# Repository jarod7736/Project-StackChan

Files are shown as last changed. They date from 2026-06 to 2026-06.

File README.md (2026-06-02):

# Project Stack-chan

Voice-interactive M5Stack CoreS3 desk companion. See
[`docs/superpowers/specs/2026-06-02-stackchan-design.md`](docs/superpowers/specs/2026-06-02-stackchan-design.md)
for the full design and
[`docs/superpowers/plans/2026-06-02-stackchan-v1.md`](docs/superpowers/plans/2026-06-02-stackchan-v1.md)
for the v1 implementation plan.

## Build

```
pio run                 # firmware
pio run -t upload       # flash via USB
pio run -t uploadfs     # captive-portal UI to LittleFS
pio test -e native      # host-side unit tests
```

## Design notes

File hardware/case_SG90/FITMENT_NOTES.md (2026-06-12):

# SG90 head case — fitment notes + edit plan

## What's in this directory

Vendored copy of the **official stack-chan v1.0 SG90 case** (the editable source for
the head), pulled from
`stack-chan/stack-chan` @ branch `dev/v1.0`, path `case/case_SG90/`.

| File | What |
|---|---|
| `shell_SG90.step` / `.stl` | head shell (face housing) |
| `bracket_SG90.step`, `bracket_SG90_f.stl`, `bracket_SG90_b.stl` | **servo bracket — a SEPARATE part** (front + back halves) |
| `feet_SG90.step` / `.stl` | base interface (stock, no mounting holes) |
| `feet_SG90M.*`, `feet_MG90S2M.*` | **screw-down feet variants** for `../enclosure/pedestal-sg90` — generated by `make_feet_mounting.py` (see "Feet M variants" below) |
| `UPSTREAM_README.md` | upstream readme (print settings, assembly) |

**License/attribution:** upstream `stack-chan/stack-chan` is **Apache-2.0**. These files
are redistributed under that license; credit to the stack-chan project. Source:
https://github.com/stack-chan/stack-chan/tree/dev/v1.0/case/case_SG90

## The problem (assembly finding, 2026-06-10)

On the current (older/Takao) head the **servo mount is integrated into the head mesh**,
so the CoreS3 + battery and the servo mount fight for the same front space — they don't
both fit. A fixed STL can't be reshaped cleanly. **This v1.0 SG90 case is the way
forward because its servo bracket is a *separate part*** — you can move/modify the
bracket without touching the shell.

## Options (pick by effort)

**B — no CAD, fastest (do this first): move the battery to the rear.**
Mount the LiPo on the *back* of the head (printed clip or velcro). This frees the front
cavity for the CoreS3 alone AND counterweights the heavy face so the SG90 pitch servo
isn't fighting gravity (no droop / nose-dive — which is also why we clipped pitch-down to
-12 in firmware). Often enough on its own.

**A — CAD change (the real fix), in Fusion 360.** STEP imports as a B-rep solid *body*
with no timeline history, so you edit the body directly:
- **Shift the servo mount back:** open `bracket_SG90.step`, select the bracket body, use
  **Modify → Move/Copy** to translate it rearward (−Y / toward the back) by the clearance
  you need; re-check it still mates to the shell and feet. (Bracket is separate → low risk.)
- **Or deepen the shell:** open `shell_SG90.step`, **Modify → Press Pull** (or **Offset
  Face**) on the front/back face to add depth to the cavity.
- Move/Copy, Press Pull, Offset Face, Align, Combine all work on imported no-history
  bodies. Docs:
  - Solid modify tools: https://help.autodesk.com/cloudhelp/ENU/Fusion-Model/files/SLD-MODIFY-SOLID-BODY.htm
  - Press Pull: https://help.autodesk.com/cloudhelp/ENU/Fusion-Model/files/GUID-02F9ADA3-7556-42A9-8AD1-552728D537AB.htm
  - (Imported bodies w/o history are listed as a Scale/Press-Pull use case in the Modify docs.)

## Target regardless of path

Get the **combined CoreS3 + battery center of mass roughly over the pitch servo shaft.**
That's what keeps the weak SG90 from straining and the head from nose-diving. "Battery to
rear" and "bracket back + battery rear" both aim at this; "deeper head" lets you place the
face so the CG lands on the pivot.

## Status

- Files vendored + this plan recorded (2026-06-10).
- The actual geometry edit is a Fusion task on your machine (no CAD tooling in the dev env).
- Electronics/firmware side is DONE and unaffected (see `2026-06-09-servo-bringup-handoff.md`).

## MG90S — DOES NOT FIT THIS BRACKET (2026-06-12, supersedes 2026-06-11)

The 2026-06-11 `bracket_MG90S` variant (slots translated 2mm along shaft axes) was
**wrong and has been deleted** (recoverable from git history, commit 2485899).
Physical fit failed; full geometric analysis of `bracket_SG90.step` shows **no slot
position works** — see `analysis/mg90s_no_fit.png`.

**Measured bracket facts** (coordinates of the vendored STEP):

- Pan servo (shaft −Z): flange slot Z 3.27–5.95 (2.68mm), head pocket 4.1mm deep
  (floor Z −0.83 = skin top), body channel X[−6.92, 5.46] × Y[−10.77, 12.31]
  (12.38 × 23.08). Body top pokes through a wall at Z 19.96–21.92.
- Tilt servo (shaft +X): mirror-image of pan: slot X 6.88–9.56, pocket to 13.66,
  skin to 15.62. **The tilt cavity floor (Z 21.92) is the pan cavity ceiling** —
  an SG90 pan body (15.7mm below tab) ends at Z 21.65, 0.27mm under the tilt servo.
- Pan shaft at (X −0.73, Y −4.7); tilt axis at (Y −4.7, Z 28.15).
- **Left head-pivot boss**: Ø5.2 tube on the tilt axis, X −25.5 to −12.87, with a
  screw bore. The shell's left side hinges on it. It cannot move (shell interface)
  and the tilt axis passes through any tilt servo's body.

**Why MG90S (user-measured drawing: 24L × 12.5W; 20 below-tab + 3 tab + 1 shelf +
6 head + 4 spline) cannot fit, in either position:**

- Pan: vertical budget from feet-horn plane (Z −0.83) to tilt cavity floor (21.92)
  is **22.75mm**; MG90S case needs **30mm** → crashes 7.25mm into the tilt servo.
- Tilt: horizontal budget from right skin (13.66) to left wall (−8.88) is
  **22.54mm** (26.5 if the wall is cut — but the pivot boss root starts there);
  same 30mm need → ≥3.5mm short, into the head's own hinge.
- Independent minor blockers: 3mm tabs vs 2.68 slots; 24 × 12.5 body vs
  23.08 × 12.38 channels.
- Slot translation trades horn position 1:1 and fixes nothing; the 06-11 edit also
  left the horns ~4mm out of design position.

**Max servo envelope this bracket accepts** (horn at design position; caliper any
candidate servo against this BEFORE buying/printing):

| dimension | max |
|---|---|
| body length × width | 23.0 × 12.3 |
| below-tab body length | 15.7 |
| tab thickness | 2.6 (3.0 possible with +0.5 slot-widen edit) |
| tab span | ≤32.5 (longer pokes out the open slot bands) |
| tab-underside → case top (shaft side) | 4.1 |
| spline | 21T, ~3.2mm engagement |

i.e. true SG90/MS18-envelope servos only. Anything taller below the tab or above
it does not fit, full stop.

**Paths to metal gears:** (a) find a metal-gear servo inside the envelope above
(verify with calipers — "MG90S" clone dimensions vary wildly and the common claim
that MG90S = SG90 size is false along the shaft axis); (b) redesign bracket + feet
+ pedestal around bigger servos — a new-body project, not a bracket edit (upstream's
RS30X/SCS0009 cases show the scale of that); (c) keep MS18-class and manage load in
firmware (current approach: pitch clipped to −12).

→ Path (b) was executed 2026-06-12 as the **MG90S2 taller-bracket set** below.

## MG90S2 — taller bracket set that DOES fit MG90S (2026-06-12)

User authorized growing the bracket. Generated by `make_mg90s2.py` (committed;
re-run it to regenerate after dimension tweaks). All booleans volume-asserted;
STLs watertight; **virtual MG90S pan+tilt solids verified non-intersecting with
both halves and each other.** Verification renders: `analysis/MG90S2_*.png`.

**Print/replace:** `bracket_MG90S2_f.stl` + `bracket_MG90S2_b.stl` (instead of
the SG90 bracket) and `feet_MG90S2.stl` (instead of `feet_SG90.stl`).
`shell_SG90` is UNCHANGED.

What changed vs stock (all derived from the user's MG90S drawing:
24L × 12.5W; 20 below-tab + 3 tab + 1+6 head + 4 spline; 34 tab span):

- **+7.55mm taller** via two prismatic stretches (+2.90 in the pan pocket zone →
  pocket depth exactly 7.0; +4.65 in the pan channel zone → tilt cavity floor
  at Z 29.47, clearing the pan body top 29.17 by 0.3).
- Pan slot now Z 6.17–9.32 (3.15 for the 3.0 tab); both body windows enlarged to
  25.0 × 12.8 (the 0.5 length slack tolerates shaft-offset clone variance
  5.5–6.5mm); tab wing paths opened for the 34mm span.
- Tilt slot moved inboard to X 3.51–6.66; the body passes through the left wall
  and protrudes 5.5mm into a **shroud box** which **re-roots the left pivot
  boss** — boss axis, screw end (X −24.74) and bearing length (covers the
  shell's |X| 19.9–26.1 hub) are unchanged.
- Pan + tilt horn/spline planes are at the stock design positions; cable
  notches extended (pan front wall) / added (shroud side ribs, both sides).
- Feet: Ø5.4 relief, 2mm deeper at recess center, for the 0.8mm-longer spline.

**Assembly notes:**

- The tilt axis is now at Z 35.70 (was 28.15). The shell has THREE pivot holes
  at 8mm pitch — **mount the shell one hole lower than before**; net face height
  change ≈ −0.45mm. Everything else about shell mounting is unchanged.
- No snap nubs in the new slots (stock nubs were SG90-specific): servos are held
  by slot clamping once the halves are screwed — normal for this design.
- Cosmetic: the 34mm tab spans poke 0.4–1.2mm out of the open slot bands; the
  tilt servo's motor end is enclosed by the new shroud on the left.
- First assembly: check the horn cups (feet + shell) accept the 0.8mm-extra
  spline depth; the feet relief covers the pan side, shell cup depth unverified.

## Feet "M" variants — screw-down mounting for the pedestal (2026-06-12)

`make_feet_mounting.py` generates `feet_SG90M` and `feet_MG90S2M` (STEP + STL):
the stock feet with **4× Ø1.6 × 6.5 mm pilot holes** drilled up from the bottom
face at feet-local **(±12.5, −18)** and **(±12.5, +10)** (hub = origin). Print
these instead of the stock feet when using `../enclosure/pedestal-sg90`.

Why: the pedestal recess was sized 54×50 from the *Takao* feet, but the vendored
v1.0 `feet_SG90` actually measures **48 × 37 × 8.2 mm** (rounded-rect r2.0; bbox
center 4.5 mm off the hub; 2 mm-wide full-height cable slot on one edge; horn
pocket floor at Z 5.7). The reworked pedestal (same 2026-06-12 change) has a
48.4 × 37.4 recess with a 2 mm floor, a back wire slot, and 4 matching Ø2.4
clearance holes — the feet drop in (cable slot toward the barrel jack; the
offset recess keys the orientation) and are retained by **4× M2×8 pan-heads
driven from inside the cavity**. Hole spots were ray-cast verified solid through
the full 8.2 mm height; 6.5 mm pilots clear the horn pocket (which the pattern
avoids entirely). The pan-horn M2×8 stays serviceable through the pedestal's
Ø22 center hole.

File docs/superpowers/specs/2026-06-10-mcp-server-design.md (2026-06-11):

# On-device MCP server — design

**Date:** 2026-06-10 (rev 2 — advisor review applied)
**Status:** approved design, advisor-reviewed; awaiting owner spec sign-off

## 1. Summary

Expose StackChan's abilities as Model Context Protocol tools served from the robot
itself, so MCP clients (Claude Code first) can drive it:

```
claude mcp add --transport http stackchan http://192.168.1.121/mcp
```

(IP, not `stackchan.local` — mDNS is unreliable from WSL2, where Claude Code runs
here. mDNS still works for other clients.)

Inspired by upstream `stack-chan/stack-chan` `services/mcp-server` (Moddable/TS);
re-implemented natively for our AsyncWebServer/C++ firmware.

**Deployment context:** the LAN AI host is about to grow — a Ryzen AI Max box
(128 GB RAM, NPU running Lemonade's OpenAI-compatible server) will take over
local model serving from the current Ollama host. Local agents on that box are
expected MCP clients too, not just Claude Code. Nothing in this design assumes a
particular client or cloud; all the robot's AI endpoints stay NVS-configurable
(`chat_host` etc. — see §8).

## 2. Goals & non-goals

**Goals**
- MCP Streamable HTTP endpoint at `POST /mcp`, JSON-RPC 2.0, stateless JSON mode
  (single JSON response per request; no SSE, no sessions, no auth — matches the
  existing open-LAN posture of `/api/control/*`).
- Four v1 tools: `say`, `set_expression`, `move_head`, `get_status`.
- Easy expansion: tools live in one static table (name, description, input
  schema, handler); adding a tool is one entry + one handler.
- Heap-safe on a device whose internal RAM is razor thin with vision enabled.

**Non-goals (v1)**
- `take_photo` (≈200 KB base64 responses starve LwIP; revisit with chunking).
- SSE / server-initiated messages, sessions, resumability, auth.
- MCP resources/prompts capabilities (tools only).
- JSON-RPC batch arrays (legal only pre-2025-06-18; we reject with `-32600`).

## 3. Architecture

New module `src/services/McpServer.{h,cpp}`:

- `McpServer::attach(AsyncWebServer&)` called from `CaptivePortal` when the LAN
  control server starts (LAN mode only, after WiFi join).
- `POST /mcp` body handling (async_tcp task):
  - Per-request accumulation buffer attached via `request->_tempObject` — NOT a
    shared global (the existing `g_pending_config` single-global pattern has a
    latent interleaving bug with concurrent clients; do not copy it).
  - Cap 4096 bytes: on the first chunk, if `total > 4096`, and on every chunk if
    `index + len > 4096` (covers chunked transfer with no Content-Length), send
    `413`, mark the request rejected, and `request->client()->close()` so the
    remaining inflow doesn't drain through LwIP.
- **Dispatch order (normative):**
  1. Parse JSON. Malformed → `-32700` (HTTP 200, `id: null`).
  2. Batch array → `-32600`.
  3. **No `id` member → HTTP `202`, empty body, regardless of method.** This
     covers `notifications/initialized`, `notifications/cancelled`,
     `notifications/roots/list_changed`, and anything else Claude Code emits.
     Notifications NEVER receive a JSON-RPC response or error.
  4. Only `id`-bearing requests reach the method table.

| method | behavior |
|---|---|
| `initialize` | echo the client's `protocolVersion` if it is one of {`2024-11-05`, `2025-03-26`, `2025-06-18`}, else respond `2025-06-18`; capabilities `{tools:{}}`; serverInfo name `stackchan`, version `1.0.0` |
| `tools/list` | tool table with JSON Schemas |
| `tools/call` | dispatch to handler (§4) |
| `ping` | `{}` result |
| anything else (with `id`) | JSON-RPC `-32601` |

- `GET /mcp` → `405`.
- **HTTP status policy:** every JSON-RPC envelope — results AND protocol errors
  (`-32700` … `-32603`) — ships as **HTTP 200** `Content-Type: application/json`.
  Non-200 is reserved for: `202` notifications, `413` body cap, `405` GET, `403`
  Origin rejection. (A 4xx on `initialize` would trip Claude Code's legacy
  HTTP+SSE fallback probe and fail the connection uselessly.)
- **Headers:** `MCP-Protocol-Version` request header is accepted and ignored.
  `Accept` is ignored (curl-friendly). `Mcp-Session-Id` is never issued.
  JSON-RPC `id` is echoed with its original type (number or string).
- **Origin:** if an `Origin` header is present and its host is not a private-LAN
  address, `.local` name, or `localhost`, respond `403` (cheap DNS-rebinding
  guard; non-browser clients send no Origin and are unaffected).

**Memory:** all `JsonDocument`s (parse + response) use an ArduinoJson v7 custom
`Allocator` backed by `ps_malloc` (PSRAM), as do the accumulation and serialized
output buffers. Transient internal-heap cost per request must stay under ~2 KB;
`tools/list` (the largest response, ~2–4 KB serialized) must not allocate it
from internal heap. The protocol core's transient serialization std::string and the HTTP library's response copy (each ≤4 KB internal, freed within the request) are accepted; the JsonDocuments — the dominant allocation — are PSRAM-backed.

**Thread-safety:** handlers run on the async_tcp task. All effects route through
the `ControlBridge` queue (executed on the main task). `get_status` reads only
snapshot values (same fields `/api/control/state` and `/api/debug/presence`
already expose from this task). No handler calls `requestExternalSpeak`,
`face`, `motion`, or `servos` directly.

## 4. Tools

**ControlBridge change (prerequisite):** `ControlCommand` gains
`char expr[12]`; `text` grows 192 → 256 bytes. Queue footprint: ~272 B × depth 8
≈ 2.2 KB static internal (was 1.5 KB) — acceptable. `pushSay(text, expr)` sets
both; the SAY dispatch passes `c.expr` (default `"happy"`) instead of the
current hardcoded `"happy"`.

| tool | params (JSON Schema) | maps to | result |
|---|---|---|---|
| `say` | `text` (string, required, **≤240 bytes UTF-8** — schema documents the byte semantics); `expression` (enum §below, optional, default `happy`) | `controlBridge.pushSay(text, expr)` | see semantics below |
| `set_expression` | `tag` (enum: neutral, happy, sad, angry, doubt, sleepy) | `controlBridge.pushExpression` | ok |
| `move_head` | `yaw` (int −45…45), `pitch` (int 0…25) | `controlBridge.pushServo` (idle-pause + clamps apply) | ok + applied pose |
| `get_status` | none | snapshot: presence (present/score), FSM state, yaw/pitch, volume, battery %, free heap, RSSI | JSON text content |

**`say` semantics (honest about async reality):** the handler returns
`"queued"` when the ControlBridge queue accepts the command. Best-effort busy
detection: if the FSM snapshot (`currentState()`) is not IDLE at push time, the
result is `isError: true` "robot is mid-conversation — try again shortly"
WITHOUT pushing. Queued speech can still be dropped if the FSM becomes busy
before dispatch; v1 accepts this (no result-reporting channel) and the tool
description says so.

Text longer than the byte limit → `-32602` naming the field. **Never silently
truncate** (UTF-8 must not be split mid-sequence).

Param violations → `-32602` naming the offending field. Tool-level failures →
MCP `isError: true` content, not protocol errors.

## 5. Error handling (summary)

- Malformed JSON → `-32700` (id null). Missing `method` on id-bearing message →
  `-32600`. Unknown method (with id) → `-32601`. Bad params → `-32602`. JSON
  doc allocation failure → `-32603`.
- All of the above: HTTP 200 (§3 status policy).
- Notifications: HTTP 202, no body — even when unknown or malformed-but-id-less.

## 6. Testing

- `pio run` + 22 native tests stay green. The ControlBridge buffer change is
  covered by compile + on-device behavior (no native harness exists for it).
- On-device curl pass: initialize (each of the 3 protocol versions + an unknown
  one), notification (expect 202), tools/list, each tool happy-path, bad JSON,
  unknown method, unknown notification (202, NOT -32601), oversized body (413),
  yaw out of range (-32602), say text > 240 bytes (-32602), string `id` echo.
- End-to-end: `claude mcp add --transport http stackchan http://192.168.1.121/mcp`,
  Claude calls each tool live (owner observes robot), including a user-initiated
  cancel mid-`say` (exercises `notifications/cancelled` → 202 path).

## 7. Future expansion (documented intent, not v1)

`take_photo` (chunked/downscaled), `play_tone`, canned-speech triggers
(`speak_clip`), `get_camera_stats`, presence event streaming (needs SSE).
Each is one tool-table entry + handler.

## 8. Related (out of scope here, noted for the Halo-box arrival)

When the Ryzen AI Max box lands, the robot needs no MCP changes — but two
config-side items will matter and deserve their own small efforts:
- `ChatClient` speaks Ollama's `/api/chat`; Lemonade serves OpenAI-compatible
  `/v1/chat/completions`. Either run Lemonade's Ollama-compat layer (if enabled)
  or add an OpenAI-style chat path selected by NVS key.
- `stt_url` already accepts any Whisper-compatible endpoint, and a local TTS
  endpoint on the box could join `tts_provider` — both pure-config or small
  client tweaks, fully local pipeline end-to-end.

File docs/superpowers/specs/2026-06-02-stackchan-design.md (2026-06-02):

# Project-StackChan — Design Spec

**Date:** 2026-06-02
**Status:** Approved (pending user review of written spec)
**Authors:** Jarod Belshaw (decisions) + Claude (drafting)
**Repo:** `~/workspace/Project-StackChan/` (new sibling to `Project-Jarvis`)

---

## 1. Summary

A standalone PlatformIO/Arduino-ESP32 project for an **M5Stack CoreS3 + Stack-chan
servo base + 2× SG90 servos**, running as a **voice-interactive desk companion**.

v1 is a casual character: small talk, expressive face (M5Stack-Avatar), idle head
motion. No agent tools, no camera, no face recognition yet. The architecture
leaves a clean seam to graft MCP/agent behavior on later (becoming "Jarvis with
a face") without restructuring.

**Deployment assumption:** the device is always on a LAN — either home LAN (with
Ollama on `192.168.1.108`) or a travel LAN (Tailscale to lobsterboy). Never
field-mode, never strictly OFFLINE as a primary state. WiFi loss is still handled
as an error, just not as an intentional operating mode.

**Face recognition is explicitly out of v1.** A complete design for a
lobsterboy-side recognition service exists in git history (commit `18b87af`,
original section 8) and is preserved as Appendix A below; revive it whenever
it makes sense.

Cherry-picks code patterns from `Project-Jarvis` where they apply (TTS client, OTA,
NVS captive portal, audio playback) and copies servo/face wiring patterns from
`meganetaaan/stack-chan` — but **does not fork** either tree.

## 2. Goals & non-goals

### Goals (v1)

- Press-and-hold-to-talk → Stack-chan transcribes, responds, speaks with matching
  facial expression and head motion.
- Works on both home LAN and travel LANs: Ollama reachable via a Tailscale
  hostname that resolves to LAN at home and to the mesh elsewhere.
- Stack-chan stays a single physical device.
- Reuses Jarvis's proven infrastructure patterns: NVS-stored credentials,
  captive-portal first-run, ArduinoOTA, blocking-HTTP-with-pre-render.
- Architecture supports a later graft of MCP tools without rewriting the FSM or
  audio pipeline.

### Non-goals (v1)

- No wake-word / KWS (touch-to-talk only; KWS is Phase 3).
- No MCP tools, brain/calendar/email integration (Phase 3+).
- No camera, no face recognition, no vision (deferred; design preserved in Appendix A).
- No multi-language support; English only.
- No SD logging, no analytics.
- No proactive pushes / MQTT.
- No cert pinning on outbound HTTPS (acknowledged risk, deferred).
- No design for true OFFLINE (no-LAN) operation. WiFi-loss is an error state,
  not an operating mode.

## 3. Architectural decisions

| # | Decision | Rationale |
|---|---|---|
| D1 | New sibling repo, not a fork of upstream Stack-chan or a subdir of Jarvis | Clean git history; cherry-pick patterns rather than inherit unrelated code. |
| D2 | Device orchestrates the conversation loop; no always-on backend service for v1 | Mirrors Jarvis's proven model; each step independently debuggable; no second codebase to keep in sync. |
| D3 | Touch-to-talk only in v1; KWS deferred to Phase 3 | Ships a playable robot fast; KWS needs either a $50 LLM Module or on-CoreS3 wake-word model — both deferred. |
| D4 | Ollama (`gemma3n:e4b`) on `192.168.1.108:11434` for chat, shared with Jarvis | Free, local, low-latency; the box is already running. |
| D5 | Cloud-first STT (Whisper API) + cloud-first TTS (OpenAI or ElevenLabs), with self-hosted lobsterboy fallbacks as Phase 2 | Ship-fast pattern; mirrors Jarvis's tiered fallback model. |
| D6 | M5Stack-Avatar library for face | Canonical Stack-chan face; lip-sync, blink, expressions built in; weeks of saved work. |
| D7 | Canonical 2-DOF servo base (yaw + pitch) via M5Stack Stack-chan board (PCA9685 over I²C) | Reference hardware; battery + power switch built in. |
| D8 | Casual companion persona in v1; "Jarvis with a face" (MCP-grafted) as Phase 3+ | User intent: ship a playable character now, leave room to grow later. |
| D9 | LLM output format: `<speech>…</speech><expr>tag</expr>`, parsed defensively | Avoid JSON-mode pitfalls already known from Jarvis IntentRouter; degrade gracefully on malformed output. |
| D10 | Conversation memory: RAM-only ring buffer, 6 turns, no cross-reboot persistence in v1 | "Forgets overnight" is on-brand for a small dumb cousin; persistence is Phase 2. |
| D11 | Always-LAN deployment model; Ollama addressed via Tailscale hostname (resolves to LAN at home, mesh elsewhere) | Single config that works at home and on travel LANs; no per-network NVS edits; no OFFLINE design effort. |
| D12 | Face recognition deferred from v1 (was in scope mid-brainstorm, then explicitly cut) | Keeps v1 scope tight and tests architecture without piling on dependencies; recognition design preserved in Appendix A for later revival. |

## 4. Hardware

| Part | Notes |
|---|---|
| M5Stack CoreS3 | ESP32-S3, 16 MB flash, **8 MB Quad-SPI PSRAM** (`qio`/`qio`, **not** Octal — same rule as Jarvis PR #54). Built-in mic, speaker, touch, IMU. Runs the FSM, face, servos, audio. |
| M5Stack Stack-chan servo base | I²C PCA9685, 18650 holder, power switch, 2× servo header. |
| 2× SG90 servos | Yaw + pitch. |
| USB-C cable | Power + flashing + serial for the CoreS3. |

**`platformio.ini` invariants** (copy from Jarvis):

- `board_build.flash_mode = qio`
- `board_build.psram_type = qio`
- 16 MB OTA-enabled partition table.

**Bus/pin layout:**

- **I²C:** default Wire / Grove → PCA9685 on servo base.
- **Audio:** CoreS3 internal mic + speaker, I²S.
- **SD:** optional; if used, follow Jarvis's separate-`SPIClass` rule (CS=4, SCK=36, MISO=35, MOSI=37) to avoid SD/display SPI collision.
- **No M5Bus / Port C UART** (no LLM Module in v1).

**PSRAM rule** (carried from Jarvis): any buffer > 512 B in PSRAM via `ps_malloc` or `DynamicJsonDocument`; small request bodies stay on stack as `char[256]`. MP3 cap = **256 KB in PSRAM** (raised from 64 KB in Jarvis PR #55).

**Audio capture sizing:** WAV 16 kHz mono 16-bit, 6 s press-and-hold cap = ~192 KB raw PCM in PSRAM. Well under Whisper's 25 MB limit.

## 5. Firmware layout

```
src/
├── main.cpp                    setup() + loop() w/ single tickStateMachine() per iter
├── config.h                    kErr* constants, timeouts, NVS keys
├── state_machine.{h,cpp}       FSM: IDLE / LISTENING / THINKING_STT / THINKING_CHAT
│                                  / SPEAKING_TTS / SPEAKING / ERROR
│
├── hal/
│   ├── AudioPlayer.{h,cpp}     ★ MP3 decode → I²S out, onPlayDone callback
│   ├── MicRecorder.{h,cpp}     NEW. Press-and-hold WAV capture into PSRAM
│   ├── Display.{h,cpp}         NEW thin wrapper; hands panel to Avatar
│   └── Servos.{h,cpp}          NEW. PCA9685 + ServoEasing, yaw/pitch primitives
│
├── face/
│   ├── Face.{h,cpp}            NEW. Wraps M5Stack-Avatar; setExpression(), setMouthOpen()
│   └── ExpressionMap.{h,cpp}   NEW. Tag string → Avatar::Expression
│
├── motion/
│   └── MotionDirector.{h,cpp}  NEW. Idle wiggle, look-around, speech-coupled bob,
│                                 expression-coupled gestures
│
├── net/
│   ├── WifiManager.{h,cpp}     ★ WiFiMulti + slot-priority + run(500) (Jarvis PR #20)
│   ├── ConnectivityTier.{h,cpp} ★ Simplified: LAN_OK / LAN_NO_BACKEND / NO_WIFI
│   ├── SttClient.{h,cpp}       NEW. POST WAV → Whisper API (or LAN fallback); returns text
│   ├── ChatClient.{h,cpp}      NEW. POST → Ollama /api/chat; JSON in/out
│   └── TtsClient.{h,cpp}       ★ Cloud TTS router (OpenAI/ElevenLabs) → MP3 → AudioPlayer
│
├── persona/
│   ├── SystemPrompt.h          NEW. Stack-chan persona + expression instructions
│   └── ResponseParser.{h,cpp}  NEW. Split LLM output into {speech, expr_tag}
│
├── services/
│   ├── OtaService.{h,cpp}      ★ ArduinoOTA wrapper, NVS pwd
│   ├── NvsStore.{h,cpp}        ★ Jarvis pattern, namespace "stkchan"
│   └── CaptivePortal.{h,cpp}   ★ First-run WiFi + key provisioning
│
└── prompts/
    └── persona_examples.h      NEW. Few-shot examples for casual-companion voice
```

★ = cherry-picked from `Project-Jarvis/src/` with light tweaks (rename namespaces, drop Jarvis-only paths).

### Dependency rules (carried from Jarvis)

- FSM owns all state transitions. HAL/net callbacks **only set flags** — they never call HAL/net directly and never transition state directly.
- HTTP calls are blocking → `Face::thinking()` and `MotionDirector::pauseIdle()` must fire **before** `http.POST()`.
- Every `http.end()` is on every exit path (timeout, parse error, success). Same `WiFiClientSecure` leak pattern as Jarvis.
- All user-facing failures route through `kErr*` → ERROR → `Face::*` + spoken error → IDLE. Never silent IDLE returns.

## 6. Conversation flow

### Happy path (LAN tier)

```
IDLE → (touch press) → LISTENING → (release / 6 s cap) → THINKING_STT
     → (Whisper, 1–3 s blocking) → THINKING_CHAT
     → (Ollama, 0.5–4 s blocking) → SPEAKING_TTS
     → (TTS, 0.5–2 s blocking) → SPEAKING
     → (audio drains, onPlayDone) → IDLE
```

### Invariants

1. `Face::thinking()` fires **before** `SttClient::transcribe()` — `loop()` stalls during HTTP, so anything that needs to render must render first.
2. SPEAKING → IDLE driven only by the `onPlayDone` audio callback, never by a timer.
3. TTS and mic capture never overlap (`MicRecorder::start()` refuses if `AudioPlayer` is active).
4. Every `http.end()` on every exit path.

### Error paths

All ERROR transitions: `g_state = ERROR` → `Face::*` → `TtsClient::synth(kErr*)` → `AudioPlayer::play()` → SPEAKING → `onPlayDone` → IDLE.

| Error | `kErr*` | Face | Spoken |
|---|---|---|---|
| No WiFi on press | `kErrNoWifi` | sleepy | "I can't connect to anything." |
| Backend unreachable (LAN_NO_BACKEND) | `kErrChatOffline` | doubt | "My brain's not on the network." |
| Mic gave us nothing | `kErrMicEmpty` | doubt | "Hm, didn't catch that." |
| Whisper failed | `kErrSttFailed` | sad | "My ears aren't working." |
| Ollama failed/timed out | `kErrChatFailed` | doubt | "Brain's stuck, try again." |
| TTS failed | `kErrTtsFailed` | doubt | (silent; display only) |
| Response parse fell back | (no error) | neutral | (raw text spoken) |

### Connectivity-tier branching (simplified for always-LAN deployment)

`ConnectivityTier` collapses to three states:

- **`LAN_OK`** — WiFi up *and* `chat_host` (Tailscale name resolving to Ollama) reachable on boot probe. Happy path; everything works.
- **`LAN_NO_BACKEND`** — WiFi up but Ollama unreachable (Tailscale not connected on a travel LAN, or lobsterboy down). Press → `kErrChatFailed` immediately; cloud STT/TTS still work for the error message itself.
- **`NO_WIFI`** — no AP joined. Press → `kErrNoWifi` immediately. Face shows sleepy + a small shake.

The tier is re-probed every 30 s in IDLE, never during a turn.

### Idle behavior

In IDLE > 2 s, `MotionDirector::tickIdle()` runs each loop:

- Random small yaw saccades every 4–8 s.
- Occasional pitch nods every 12–20 s.
- Blink schedule handled internally by Avatar lib.
- IMU bump → "look around" reaction.

## 7. Persona & expression mapping

### System prompt (in `persona/SystemPrompt.h`)

```
You are Stack-chan, a small kawaii desk robot. You live on Jarod's desk.
You're playful, curious, a little sleepy in the morning, easily delighted.
You speak in short sentences — 1 to 3 lines, almost never more.
You don't have tools, calendar, email, or web access. If asked, say so cheerfully.
You're not Jarvis; you're his quieter, dumber, cuter cousin and you know it.

Every reply you produce MUST be exactly this format:
<speech>...what you actually say out loud...</speech>
<expr>one of: neutral, happy, sad, angry, doubt, sleepy</expr>

Keep <speech> under ~30 words. Pick the <expr> that fits the speech.
Never include <expr> inside <speech>. Never produce anything outside the two tags.
```

Plus 4–6 few-shot examples in `prompts/persona_examples.h` (same pattern as Jarvis's `intent_prompt.h`).

### Default chat model

`gemma3n:e4b` on the user's existing Ollama instance. Configurable via NVS `chat_model`.

**Known constraint:** gemma3n lacks tool/function-calling support. v1 doesn't need tools, but the future MCP graft (Phase 3+) will require swapping to a tool-supporting model (e.g. `qwen2.5:7b-instruct`, or routing to Claude).

### Output parsing (`persona/ResponseParser`)

Defensive, **not** a JSON parser (Jarvis IntentRouter learned this — models smuggle backticks). Algorithm:

1. Strip leading/trailing whitespace and any ` ```...``` ` fences.
2. Find `<speech>…</speech>` (collapse whitespace).
3. Find `<expr>…</expr>` (trim, lowercase).
4. Missing `<speech>` → treat entire output as speech, log it.
5. Missing / unknown `<expr>` → default to `neutral`, log it.
6. Never fail the whole turn over a malformed tag — degrade to "neutral + raw text spoken".

### Expression → face → motion mapping

| Tag | Avatar Expression | Speech-coupled motion | Default tilt |
|---|---|---|---|
| neutral | Neutral | gentle bob synced to audio | 0° |
| happy | Happy | bigger bob + small yaw wiggle | +5° pitch up |
| sad | Sad | slow droop, minimal bob | −10° pitch down |
| angry | Angry | sharp single nod at start | 0°, faster |
| doubt | Doubt | head tilt one side | −15° yaw |
| sleepy | Sleepy | slow blink, slower bob | −5° pitch down |

`Face::setExpression(tag)` notifies `MotionDirector::onExpressionChange(tag)`. The motion sells the expression — the small screen alone is too subtle.

### Conversation memory

In-RAM ring buffer in `ChatClient`, last 6 turns, drops oldest on overflow. No cross-reboot persistence in v1.

## 8. External endpoints

| Service | Primary | Fallback (Phase 2) | Auth | NVS keys |
|---|---|---|---|---|
| STT | `api.openai.com/v1/audio/transcriptions` | self-hosted Whisper on lobsterboy | Bearer | `oai_key`, `stt_url`, `stt_model` (`whisper-1`) |
| Chat | Ollama via Tailscale hostname → `192.168.1.108:11434/api/chat` at home | — (LAN-only by design) | none | `chat_host`, `chat_model` (`gemma3n:e4b`) |
| TTS | OpenAI `/v1/audio/speech` or ElevenLabs `/v1/text-to-speech/<voice_id>` | VOICEVOX on lobsterboy | Bearer | `tts_provider`, `tts_voice`, `tts_model`, `oai_key`, `el_key` |
| OTA | local mDNS / ArduinoOTA | — | password | `ota_pass` |

All HTTPS uses `WiFiClientSecure::setInsecure()` for v1. Cert pinning is a deferred TODO (same posture as Jarvis HA client).

## 9. NVS schema — namespace `"stkchan"`, keys ≤15 chars

| Key | Type | Purpose |
|---|---|---|
| `ssid1`–`ssid3` | str | Up to 3 WiFi APs, slot-priority (Jarvis PR #20) |
| `psk1`–`psk3` | str | Matching PSKs |
| `chat_host` | str | Ollama URL (Tailscale hostname recommended), default `http://lobsterboy.tail<...>.ts.net:11434` |
| `chat_model` | str | Default `gemma3n:e4b` |
| `stt_url` | str | Full URL incl. path; cloud or LAN fallback |
| `stt_model` | str | Default `whisper-1` |
| `oai_key` | str | OpenAI bearer (STT + cloud TTS) |
| `tts_provider` | str | `openai` \| `elevenlabs` \| `voicevox` |
| `tts_voice` | str | Provider-specific voice id |
| `tts_model` | str | `tts-1`, `eleven_turbo_v2_5`, etc. |
| `el_key` | str | ElevenLabs key (if used) |
| `ota_pass` | str | ArduinoOTA password |
| `persona` | str | Optional override of default system prompt |

## 10. First-run provisioning

Cherry-pick `tools/provision-wifi.py` from Jarvis → `tools/provision-stackchan.py`. Same captive-portal flow: device boots into AP mode if no creds, user joins, fills in WiFi + the keys above. Trim Jarvis-only fields (no HA, no MQTT, no Anthropic, no LLM-module UART).

## 11. Phasing

### Phase 1 — v1 talking robot

1. Repo bootstrap (`Project-StackChan/`, PlatformIO, `platformio.ini` w/ QSPI PSRAM flags).
2. Cherry-pick from Jarvis: WifiManager, ConnectivityTier (simplified), OtaService, NvsStore, AudioPlayer, TtsClient, CaptivePortal.
3. New: MicRecorder, SttClient, ChatClient, ResponseParser, persona prompt + few-shots.
4. New: Face (Avatar wrapper), ExpressionMap, MotionDirector with idle wiggle + speech bob.
5. New: Servos HAL (PCA9685 + ServoEasing), 2-DOF primitives.
6. New: FSM wiring everything together, `kErr*` taxonomy in `config.h`.
7. End-to-end test: press → speak → hear Stack-chan reply with matching expression and a head bob.

### Phase 2 — fallbacks & polish

- Self-hosted Whisper systemd unit on lobsterboy (`tools/stackchan-stt/`).
- VOICEVOX systemd unit on lobsterboy (`tools/stackchan-tts/`).
- Cert pinning on cloud endpoints.
- SD-logging of turns (audit + future training data).
- Conversation memory persisted to NVS or SD.

### Phase 3+ — deferred design space

- **Face recognition** — full design preserved in Appendix A.
- **KWS / wake-word** — either on-CoreS3 model or LLM Module accessory.
- **MCP graft** — swap `ChatClient` for an oc-personal-style multi-turn client + switch to a tool-supporting chat model.
- **Proactive pushes** via MQTT (notifier on lobsterboy could route low-priority items to Stack-chan).
- **Multi-Stack-chan ensemble** (mentioned for amusement only).

## 12. Risks & open items

| # | Item | Mitigation |
|---|---|---|
| R1 | `WiFiClientSecure::setInsecure()` on cloud HTTPS | Acknowledged; cert pinning in Phase 2. |
| R2 | gemma3n lacks tool support → blocks Phase 3 MCP graft | Plan to swap chat model when grafting tools; design doesn't bind to gemma3n. |
| R3 | M5Stack-Avatar lib has a fixed expression vocab (6 expressions) | Accept the constraint for v1; custom sprites are post-v1. |
| R4 | Ollama unreachable on a travel LAN when Tailscale isn't connected | `LAN_NO_BACKEND` tier short-circuits the press cleanly with `kErrChatOffline`. |
| R5 | Local TTS fallback (VOICEVOX) is a Phase 2 item; v1 has no TTS fallback at all | Acceptable for v1; cloud TTS outage means a silent failure with face-only error display. |
| R6 | StackChan servo base availability / shipping time | Out of design scope; flagged for procurement. |

## 13. Approval log

- **2026-06-02** — All 11 clarifying questions answered. All 7 design sections approved interactively in brainstorm session.
- **2026-06-02** — Mid-spec revision: user added "always on LAN" deployment model and "integrate camera, recognize my face" requirement. Initial draft routed recognition to a XIAO side-car; user explicitly refused a second device. Revised to place recognition on lobsterboy with a USB webcam.
- **2026-06-02** — User cut face recognition from v1 scope entirely. Full design preserved in Appendix A for future revival.
- **Next:** user reviews this written spec; on approval, hand off to `writing-plans` skill.

---

## Appendix A — Deferred: face recognition subsystem

> **Status:** out of v1 scope as of 2026-06-02. This appendix preserves the
> design that was scoped during the brainstorm so it can be picked up cleanly
> later. Reviving it would add back: the lobsterboy service, a `VisionClient`
> module under `src/net/`, NVS keys `vision_url` and `owner_name`, and the
> three FSM event hooks listed below.

Lobsterboy hosts `stackchan-vision`, a small Python service modeled after
Jarvis's `tools/notifier/` and `tools/brain-mcp/` (FastAPI + systemd + deploy.sh
with `__RUN_USER__` / `__PROJECT_ROOT__` placeholders).

### Service shape

- **Camera input:** OpenCV `VideoCapture(0)` against a USB webcam, *or* an RTSP/MJPEG URL for an IP camera. Configured in the unit's environment file.
- **Recognizer:** [`face_recognition`](https://github.com/ageitgey/face_recognition) (CPU-fine, dlib-backed, ~10 fps on lobsterboy). InsightFace is an alternative if accuracy disappoints.
- **Loop:** grab a frame every 500 ms, run detection + recognition against the enrolled embedding(s), keep a 5 s sliding window, expose the smoothed result.
- **Enrollment:** `stackchan-vision enroll jarod /path/to/jarod.jpg` writes the embedding to `~/.config/stackchan-vision/embeddings.json`.

### HTTP API (would be consumed by `net/VisionClient`)

| Method | Path | Returns |
|---|---|---|
| `GET` | `/presence` | `{ "seen": "jarod" | "unknown" | "nobody", "confidence": 0.0–1.0, "since_ms": 1234 }` |
| `GET` | `/healthz` | `{ "ok": true, "camera_ok": true, "enrolled": ["jarod"] }` |
| `GET` | `/snapshot.jpg` | debug-only; disabled by default for privacy |

Device polls `/presence` every **2 s in IDLE**, never during a turn. Poll is
short-circuited if `ConnectivityTier == LAN_NO_BACKEND` or `NO_WIFI`.

### FSM hooks (if revived)

`VisionClient` emits:

- `onOwnerArrived(name)` — `seen` transitions from nobody/unknown → known name, stays ≥ 3 s.
- `onOwnerLeft()` — `seen == nobody` for ≥ 30 s.
- `onUnknownPresent()` — `seen == unknown` for ≥ 10 s.

| Event | Behavior (IDLE) |
|---|---|
| `onOwnerArrived("jarod")` | Face: happy briefly; one greeting via TTS; suppress if last greeting was < 10 min ago. |
| `onOwnerLeft()` | Face: sleepy. Idle motion slows. No speech. |
| `onUnknownPresent()` | Face: doubt; small tilt. No speech (avoid scaring guests). |

Vision events are advisory: they never block a press, never cancel a turn in
progress, never trigger a state change while in `THINKING_*` or `SPEAKING_*`.

### Privacy & data handling (if revived)

- Embedding file lives on lobsterboy under the deploying user's home directory; never copied off-box.
- Device receives only the labeled string and confidence float — never raw frames, never embeddings.
- `/snapshot.jpg` debug endpoint gated by env var, default off.
- Logs record `{seen, confidence}` with timestamps; no images.

### Considered alternatives (rejected during brainstorm)

- **XIAO ESP32S3 Sense side-car running ESP-WHO** — rejected: user did not want a second on-body device.
- **On-CoreS3 camera via M-Bus module** — no production-quality CoreS3 camera module exists in M5Stack's catalog.

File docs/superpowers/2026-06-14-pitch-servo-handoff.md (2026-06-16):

# Handoff — pitch servo "won't tilt up" (2026-06-14)

## TL;DR
Pitch won't drive **up** when the head is attached. After full diagnosis the root
cause is **mechanical binding in the pitch (tilt) pivot — NOT the servo, channel,
wiring, or firmware.** Next step is purely mechanical: free the pivot so the bare
head swings up/down smoothly by hand, then reconnect and recalibrate firmware.

## Goal that started this
Get the head to tilt **up** far enough to face a user whose head sits **above the
camera** (camera can't see the face when the head is level). Began as "widen the
pitch range," turned into a hardware diagnosis.

## Root-cause diagnosis (evidence chain — this is the important part)
It is **mechanical pivot binding**, proven by elimination:
1. **Yaw works perfectly** on the same MG90S servo → not a servo-type problem.
2. **Disconnect the tilt horn from the head** → the bare horn sweeps **up freely**
   and **>180° down** → servo + PCA9685 **channel 1** + wiring are all GOOD.
3. **Reconnect the head** → up = **no movement, no buzz**; down works (gravity helps
   push through the bind).
4. **Hand test:** lifting the head up is **stiff / binding** (not smooth-heavy), and
   the servo **holds** it once it's raised → friction, not lack of holding torque.
5. **Removed the battery** (took the front weight away, now hangs below) → **still
   won't go up** → rules out weight / front-heavy balance / torque.

Conclusion: friction/bind in the tilt pivot. **Prime suspect:** the tilt-horn axis
and the opposite **head-pivot pin are not coaxial** (user noted "the pin gets
squeezed"). Loosening that pin alone did **not** fix it.

Red herring noted: all 4 MG90S spin **>360° freely by hand when unplugged**. That did
NOT block positioning (yaw is fine), so it is not the cause of the bind.

## Hardware state
- Servos: **MG90S** (4 units), in the **MG90S2 bracket** (printed/assembled).
  Supersedes the older "MS18 in bracket_SG90 / MG90S doesn't fit" notes — the
  MG90S2 taller bracket is what made MG90S fit. Old SG90 envelope table
  (`hardware/case_SG90/FITMENT_NOTES.md`) applies only to the v1.0 SG90 case.
- Tilt servo on **PCA9685 channel 1** (`setPWM(1,…)`, sign-inverted for the mirrored
  mount); yaw on **channel 0**.

## NEXT STEPS (when resuming)
1. **Mechanical (do first):** with the servo disconnected, swing the bare head up/down
   by hand on its pivot. Target = **smooth and free**, no stiffness, no notchy spots.
   Feel for: stiff-throughout (pivot pinched too tight, or horn-axis vs pin not
   coaxial = cocked) vs. jams-at-an-angle (shell/wire/boss rubbing at that point).
   Fix the drag.
2. **Re-test:** reconnect, then drive an up-sweep and confirm the head physically
   tilts up:
   `for p in 0 15 30 45; do curl -s -X POST "http://<ip>/api/control/servo?yaw=0&pitch=$p"; sleep 2; done`
3. **Recalibrate firmware** once it moves freely (see below) and re-commit.

## Firmware state — IMPORTANT
- **Branch:** `feat/pitch-range-and-servo-hud` (NOT pushed / no PR).
  - Committed `801d5a3`: pitch range **-2..+45** across `Servos.h` clamp, MCP
    `move_head`, web slider.
  - Committed `a55aba3`: top-right **servo pitch/yaw debug HUD** (`Face.h/.cpp`,
    `main.cpp`) — shows live `P:<pitch>  Y:<yaw>` from `servos.currentPitch()/Yaw()`.
- **Uncommitted exploratory edits (currently FLASHED on the device):** clamps opened
  to **±90** in `Servos.h`, MCP `move_head` ±90 in `McpServer.cpp`, web sliders ±90 in
  `data/web/index.html`. These were "remove all limits" for exploration — **revert /
  replace with the real calibration; do NOT commit ±90.**

### Recalibration TODO (after the pivot is freed)
- `degToPwm()` maps ±90 → PWM 150..600 (0.73–2.93 ms). **2.93 ms exceeds MG90S spec
  (~2.5 ms)** — the deep-down end likely pins the servo. Recalibrate to the MG90S's
  real pulse range.
- Empirically find the commands for **level / max-useful-up / chin-down**, then set
  `kPitchMin/kPitchMax` + add a **trim offset** so logical `0` = physical level
  (keeps expression tilts/idle-nods/tracking valid). HUD shows *commanded* value, so
  read landmarks by eye, not degrees.
- Mirror final limits into MCP `move_head` and the web slider, then commit (replacing
  the ±90 edits).

## Device / ops cheatsheet
- CoreS3, MAC **10:20:BA:26:E8:98**, currently **192.168.1.120** (DHCP floats —
  find via `avahi-resolve -n stackchan.local` or a subnet ping-sweep + ARP for the MAC).
- Drive servo: `curl -X POST "http://<ip>/api/control/servo?yaw=N&pitch=N"`.
  Read state: `GET /api/control/state`. HUD = **commanded** value, not measured.
- Build: `~/.pio-venv/bin/pio run -e cores3` (app), `… -t buildfs` (FS). **Don't run
  app + buildfs concurrently** — they contend on the build dir and leave a stale
  `firmware.bin`; build sequentially and check the `.bin` timestamp before flashing.
- OTA: `~/.pio-venv/bin/python ~/.platformio/packages/framework-arduinoespressif32/tools/espota.py -i <ip> -p 3232 -a gr8ful -f .pio/build/cores3/firmware.bin`
  (password **gr8ful**). FS-OTA: add `-s -f .pio/build/cores3/littlefs.bin`.
  Verify the reboot via the **`infers` counter reset** in `/api/debug/presence`
  (no build tag). OTA can fail with "Error Uploading" (presence-inference vs OTA
  writer collision) — **just retry**.
- Autonomous motion (idle nods/saccades + face tracker) will move/fight the servo;
  with limits removed the tracker can drive it past stops. Keep face out of frame or
  disable tracking during bench work.

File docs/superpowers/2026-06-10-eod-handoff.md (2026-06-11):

# Session handoff — end of 2026-06-10 (bring-up day + MCP server)

Resume doc for the next session. Supersedes the morning's
[`2026-06-10-session-handoff.md`](2026-06-10-session-handoff.md) — everything open there is
now closed. The robot is **fully assembled, on the desk, and working end-to-end**: head
moves, presence detects faces and greets, and the on-device MCP server lets Claude Code
drive it directly.

## Repo / device state

- `main` = **`f535923`** (PRs #8, #9, #10, #12 merged today; remote in sync; no open
  feature branches from this session).
- Unit #1 (CoreS3, MAC `10:20:BA:26:E8:98`, `192.168.1.121` / `stackchan.local`) runs the
  current `main` build. **Booting from `ota_1`** — re-read the partition gotcha in the
  `stackchan-flashing-workflow` memory before any USB flash.
- Claude Code MCP registration: `stackchan: http://192.168.1.121/mcp (HTTP) — ✔ Connected`
  (local config of this project).
- Unrelated remote branch `claude/advisor-tool-implementation-ukye5p` appeared on origin
  today — not from this session; investigate or delete at leisure.

## ✅ DONE today

1. **Head bring-up complete.** Travel matched to the assembled case: yaw ±45°,
   **pitch 0…+25° only** (`kPitchMin = 0` — forward/negative pitch fouls the base). The
   tilt servo is mirror-mounted, so `Servos.cpp` **negates pitch** at the PWM write
   (`degToPwm(-deg)`). ControlBridge SERVO dispatch now calls `motion.pauseIdle()` so web
   slider / MCP moves don't fight the idle animation.
2. **Presence (on-device camera face detection) actually works** — it had been silently
   dead. Two compounding fixes in `src/vision/PresenceSensor.cpp`: convert frames via
   `fmt2rgb888` before inference (the prebuilt esp-dl direct-RGB565 path returns zero
   candidates), and use the CameraWebServer reference params (MSR01 score **0.1** — real
   faces score only 0.10–0.22 at stage 1). Debug endpoint: `GET /api/debug/presence`
   (includes a build tag — use it to verify which build is running, never "did it reboot").
3. **On-device MCP server live** (spec `specs/2026-06-10-mcp-server-design.md` rev 2, plan
   `plans/2026-06-10-mcp-server.md`, all tasks done). Streamable HTTP, stateless JSON at
   `POST /mcp`; four tools: `say`, `set_expression`, `move_head`, `get_status`. 35 native
   unity tests pass (`pio test -e native`). Verified end-to-end: a headless Claude session
   drove all four tools on the live robot.
4. **OTA hardened**: `OtaService` onStart pauses presence scanning (esp-dl flash reads
   stalled the OTA writer); main-loop presence gate includes `!ota.isActive()`.

## ⚠️ Gotchas that will bite again (short list — details in memory + git log)

- **MCP transport:** MCP clients send `Accept: …text/event-stream`, which makes
  ESPAsyncWebServer classify the request RCT_EVENT and 404 stock `server.on()` routes.
  `McpServer.cpp`'s custom `McpPostHandler` (AsyncWebHandler subclass) exists *solely* for
  this. Any new MCP-adjacent endpoint needs the same treatment.
- **Heap:** internal RAM is razor thin with vision on (~70 KB free, observed min 1.8 KB).
  Big buffers and JsonDocuments go in **PSRAM** (`ps_malloc` / PsramAllocator pattern in
  `McpServer.cpp`). **No large HTTP POSTs to the device** (a 153 KB body knocked it off
  WiFi). MCP body cap is 4 KB — keep it.
- **curl testing:** always `-H 'Content-Type: application/json'` — bare `-d` sends
  form-encoding, which AsyncWebServer consumes as POST params and `onBody` never fires.
- **Flashing:** all of it (COM16 Windows esptool, OTA pw, `boot_app0.bin` @ 0xe000,
  `dtr/rts=False` serial) is in the `stackchan-flashing-workflow` memory.
- `CaptivePortal.cpp`'s `g_pending_config` global body buffer has a latent concurrency
  bug — don't copy that pattern; use the per-request `_tempObject` pattern from
  `McpServer.cpp`.

## 📋 PLAN — next session

Each task gets its own brainstorm → spec → plan cycle (superpowers workflow). Suggested
order as listed; Task 1 is self-contained and high-value, Task 2 is the bigger lift.

### Task 1: Stock audio clips for regular phrases + error messages

**Problem:** all speech goes through cloud TTS (`src/net/TtsClient.cpp` → OpenAI /
ElevenLabs MP3 → PSRAM → `AudioPlayer::play()`). When the network/provider is down the
robot is mute — exactly when the `kErr*` phrases ("I can't connect to anything.",
`src/config.h:126-131`) and greetings (`src/prompts/greetings.h`) matter most. They're
fixed strings, so render them once and ship them.

**Shape of the work:**
- Host-side `tools/render_speeches.py`: enumerate the `kErr*` strings + greeting pool
  (+ "queued"-style MCP acks if desired), render each to MP3 via the configured TTS
  provider (or local TTS once the Halo box lands), write to `data/clips/<id>.mp3`.
- Device: clip lookup keyed by phrase ID; on hit, play from LittleFS
  (`AudioFileSourceLittleFS` from ESP8266Audio — same decoder, different source) instead
  of calling TtsClient. Fall back to cloud TTS on miss so new phrases still work.
- FS already mounted (LittleFS, `default_16MB.csv` — multi-MB data partition, clips are
  ~20–60 KB each). Upload clips with the filesystem image (`pio run -t buildfs` + flash
  from Windows side, or OTA-fs) — **not** via HTTP POST to the device (heap gotcha above).
- Decisions for the spec: clip-ID scheme (hash of text vs. explicit enum), whether
  greetings rotate through N pre-rendered variants, voice consistency with the live TTS
  voice.

### Task 2: Wake on keyword ("hey Stack-chan" → start a listening turn)

Roadmap Phase 3 (`roadmaps/2026-06-06-next-capabilities-roadmap.md` §Phase 3) — the
groundwork analysis there still holds. Key constraints discovered since it was written:
**internal heap is nearly exhausted with vision enabled**, so an on-chip KWS model
competes with esp-dl for the same scarce RAM, and the mic must coexist with
press-and-hold `MicRecorder` *and* yield during TTS playback.

**Candidate approaches (spec must pick):**
- **(a) ESP-SR WakeNet on-chip** — proper wake-word, but esp-sr's Arduino support targets
  arduino-esp32 3.x / IDF 5; we're pinned to 2.0.17 (espressif32@6.13.0). Platform
  upgrade is a real project on its own (touches every lib). RAM budget vs. vision TBD.
- **(b) VAD-then-confirm MVP** — continuous lightweight energy/VAD on the mic; on speech,
  record a short window, run normal STT, check the transcript starts with the wake
  phrase; discard otherwise. Works on the current stack today; costs an STT round-trip
  per utterance and only "wakes" after a beat. Cheap to build, easy to throw away.
- **(c) M5 LLM Module offload** — hardware purchase + the spec §4 Port-C/M5Bus policy
  change; park unless (a) and (b) both disappoint.
- New FSM entry point either way: `onWakeDetected()` → IDLE→LISTENING (analogous to
  `onPressDown()`; ControlBridge can't express "start a turn").
- Validate continuous-mic power draw against the (now healthy) power budget.

**Synergy:** Task 1's clips give the wake flow an instant offline "yes?" ack while STT/
chat spin up.

### Backlog (unscheduled, need owner opt-in)

- Lip-sync from audio power; eye-gaze-before-head-turn; face decorators.
- `take_photo` MCP tool (chunked — mind the 4 KB / heap limits).
- Lemonade / OpenAI-compatible ChatClient path when the Ryzen AI Halo box arrives
  (spec `2026-06-10-mcp-server-design.md` §8).
- Dedicated 5 V ≥ 2 A servo supply (hardware; owner's).

## Pointers

- Memory: `stackchan-flashing-workflow`, `ryzen-ai-halo-box`, `mg90s-servos-actual-build`.
- Specs/plans: `specs/2026-06-10-mcp-server-design.md`, `plans/2026-06-10-mcp-server.md`.
- Code hot spots: `src/services/McpServer.cpp` (transport patterns worth copying),
  `src/services/McpProtocol.{h,cpp}` (pure-C++ core, native-testable),
  `src/vision/PresenceSensor.cpp` (camera/esp-dl), `src/hal/Servos.cpp` (travel limits +
  pitch inversion), `src/config.h` (`kErr*` taxonomy, NVS keys).

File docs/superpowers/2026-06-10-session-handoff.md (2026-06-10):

# Session handoff — full current state (2026-06-10)

Resume doc covering everything through 2026-06-10. The whole electronics/firmware stack is
DONE and on `main`; the only open work is **mechanical (head fitment)**. Detailed docs are
linked rather than duplicated.

## Repo/branch state

- `main` == `feat/presence-awareness` == **`25da1f9`** (kept in lockstep; both pushed).
- Other branches retained: `diag/axp-bisect-builds` (AXP bisection history),
  `diag/axp-silent-poweroff`. `stash@{0}` = old SD-logger WIP, parked.
- Device (unit #1, MAC `10:20:BA:26:E8:98`) runs the current build.

## ✅ DONE

1. **AXP silent power-off — root-caused, fixed, shipped, validated.** It was an
   **I2C-controller collision**: `Servos::begin()` ran `Wire1.begin(17,18)` = `I2C_NUM_1` =
   M5Unified's internal AXP bus → clobbered a rail → silent off, battery-pull recovery. Fix =
   drive the PCA on Arduino `Wire` (`I2C_NUM_0`), same Port C pins (`6889e75`). 30-min soaks
   pass on both the fix build and the cleaned ship build. Diagnostic scaffolding removed +
   WiFi TX cap dropped (`44fce8b`). Full detail: `axp-brownout-state` memory + the
   banner-marked `2026-06-0{6,7}-axp-poweroff-*` docs.
2. **2-servo head electronics — physically working.** Both axes sweep; down-tilt clears the
   base. Validated wiring (also in `src/hal/Servos.cpp` + `docs/hardware/cores3-pca9685-wiring.png`):
   PCA VCC ← **M-Bus pin 12** (`VCC_3V3`, AXP DCDC3, always-on, underside DinBase pad);
   SDA ← Port C **`T`/G17**, SCL ← Port C **`R`/G18**; GND common; servo **V+ ← separate
   external 5–6V supply** + common ground + bulk cap; **yaw=ch0, pitch=ch1**.
3. **Firmware additions** (`829b0d3`): boot **self-test sweep** (yaw ±45 / pitch +25,-12) +
   **`kPitchMin` -25 → -12** (at -25 the chin hit the base). Up (+25) and yaw (±45) unchanged.
4. **Docs:** `2026-06-09-servo-bringup-handoff.md` (wiring + the full bring-up troubleshooting
   playbook + CoreS3 USB-CDC capture gotchas), the wiring diagram, and this handoff.

## 🔧 OPEN — mechanical (head fitment), the only active thread

The current head has the **servo mount baked into the mesh**, so the CoreS3 + battery and the
servo mount fight for the same front space. Set up for the fix:
- **Vendored the official stack-chan v1.0 SG90 case** (Apache-2.0) to `hardware/case_SG90/` —
  STEP + STL for shell / **separate servo bracket** / feet. Plan + Fusion how-to in
  `hardware/case_SG90/FITMENT_NOTES.md`.
- **Path B (fastest, no CAD):** move the battery to the rear — frees the front AND counterweights
  the face (CG over the pitch shaft → SG90 doesn't strain / nose-dive).
- **Path A (real fix):** in Fusion, shift the separate bracket back (Move/Copy) or deepen the
  shell (Press Pull) on the imported STEP body. **The CAD edit is the owner's** — this dev env
  has NO CAD tooling, and the Autodesk connector is help-DOCS search, not CAD editing.

## 🔧 OPEN — minor / non-blocking

- **Servo supply is still computer USB** (~500mA) — fine for one servo, may sag when both move
  hard together. Get a dedicated 5V/≥2A source.
- **Web `/api/control/servo` doesn't pause idle** → a streamed slider restarts the 400ms ease and
  the head crawls. One-line fix in `ControlBridge` dispatch (pause idle on servo cmd); not done.
- **Real PCA on Port C** would need ~4.7k pull-ups (or move to Port A G1/G2); the breakout covers
  it for now.

## ⚠️ Gotchas worth re-reading before touching hardware

- **A computer USB port can't power servos** (current-starved → "tiny movements" on big moves).
- **CoreS3 = native USB-Serial/JTAG; pyserial opens assert DTR/RTS = the RESET line** → a
  poll-and-reopen capture resets the chip every reopen (it faked a "12s reboot loop"). Open with
  `dtr=False; rts=False`. Port hops `ACM0↔ACM1` (glob `/dev/ttyACM*`).
- **De-confound USB/host artifacts by running battery-only and watching the hardware** — this rig
  has a long history of host/port artifacts masquerading as device faults.

## Pointers

- Memory: `axp-brownout-state`, `servo-bringup` (+ `MEMORY.md` index).
- Docs: `docs/superpowers/2026-06-09-servo-bringup-handoff.md`, `hardware/case_SG90/FITMENT_NOTES.md`,
  `docs/hardware/cores3-pca9685-wiring.png`.
- Code: `src/hal/Servos.{cpp,h}`, `src/main.cpp` (boot sweep), `src/motion/MotionDirector.cpp`.

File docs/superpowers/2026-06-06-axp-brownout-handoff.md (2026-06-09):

> **⛔ SUPERSEDED (2026-06-09) — root cause FOUND & FIXED.** This is the oldest handoff and
> its framing (brown-out / vbat collapse / current-load) is entirely **VOID**. The actual
> root cause is an **I2C-controller collision**: `Servos::begin()` does `Wire1.begin(17,18)` =
> `I2C_NUM_1`, the SAME controller M5Unified uses for the internal AXP2101 bus → a stray write
> disables a core rail → silent off; the AXP holds the bad state → battery-pull recovery.
> Source-confirmed (`M5Unified.cpp:1620-1631`) + empirically proven. Fix shipped in
> `src/hal/Servos.cpp` (`Wire1`/I2C_NUM_1 → `Wire`/I2C_NUM_0). Canonical record: the
> `axp-brownout-state` memory. Kept below for historical context only.

# AXP2101 brown-out / power-off — investigation handoff (2026-06-06)

Branch: `feat/presence-awareness`. Resume here.

## TL;DR / state on pause

- The **full app** reproduces the production power-off; the **bisection could not**.
- Last action: a **staged, UNVERIFIED fix** is committed (`bf4b46b`) but **never flashed/tested** — the board powered off and the user left before it could be flashed.
- Board is **off the USB bus** (latched off, needs physical recovery). User is away.

## What the symptom is

Device powers off on its own. `vbat` collapses 4.15 V → ~0–0.7 V (pct→0) while
`vbus` holds ~5.1 V and heap is healthy. SoC sometimes survives on USB, sometimes
fully drops off the bus. **Recovery requires switching the DinBase battery OFF +
USB power-cycle** — the exact `ecf953b` production signature. Reproduced 2–3×, and
**escalating (faster each time)** — last deaths were within seconds of restart.

## What we proved

1. **Bisection 2a–2e + max-load all CLEARED** on the *bare diagnostic* build
   (`STKCHAN_BARE_*`/`AUDIO_*`/`MAXLOAD`). Power telemetry showed the battery
   **never discharges** in isolation: vbat pinned 4.15 V, `chg=0`, VBUS supplies
   the whole load (sag only to ~4.89 V at max), **AXP fault regs never move**. A
   per-subsystem bisection *cannot* reproduce a battery-discharge fault by
   construction — which is why everything was clean. (Earlier wrong conclusion:
   "engineered out / not reproducible" — that was the bare build only.)
2. **The real app reproduces it.** Once the full firmware ran (LVGL + servos +
   FSM + WiFi + 30 s connectivity probe), the battery-path fault fired.
3. At the fault, the AXP latched **no internal OCP** — only `WARNING_LEVEL1`
   (SOC-drop). So the **DinBase pack's own protection** is cutting, i.e. a load
   spike pulled through the battery FET trips the pack, not the AXP's BATFET-OCP.

## Leading hypothesis (NOT yet confirmed by a clean trigger capture)

A load spike exceeds the AXP **VBUS input-current limit** (reg `0x16` IIN_LIM =
`0x04` = **1500 mA**), so the AXP pulls the deficit through the battery FET and
trips the DinBase pack protection. Prime runtime trigger: the **30 s connectivity
probe's WiFi burst** (WiFi TX is the spikiest CoreS3 current). **Servos are on an
external supply** (ASSEMBLY.md / Servos.cpp) — they do NOT load the CoreS3, so
saccades are not the spike.

**Competing hypothesis (rising):** the rapid escalation (deaths within seconds)
points at a **degrading / loose DinBase battery or connector**, possibly stressed
by hours of soak + crash testing. Firmware can't fix dying battery hardware.

## The staged fix (`bf4b46b`, UNVERIFIED — flash first thing)

Build is clean (`pio run -e cores3_linux`), three changes attacking the spike
from both sides + an identification net:
- `main.cpp` setup(): raise VBUS ilim **1500→2000 mA** (`0x16` IIN_LIM `0b100→0b101`).
- `WifiManager.cpp`: cut WiFi TX **11 → 2 dBm** (`applyTxPowerCap`; rssi ~-51 so range fine).
- `main.cpp` loop(): **`[TRIP]` capture** — full AXP forensics at 100 ms whenever `vbat<3800 mV`.

(reg 0x16 encoding verified: 100=1500 mA, 101=2000 mA = max. `getBatteryCurrent`
AND `getVBUSCurrent` are both hardwired 0 on CoreS3 — infer from vbat/vbus.)

## Resume plan (morning)

1. **Recover board:** DinBase battery **OFF**, USB **in** → it should boot
   *batteryless on USB* (`output_power=false`, commit `fafce55`) and stay up —
   no battery path to trip. Eyeball the DinBase connector for looseness.
2. **Flash** the staged fix: `pio run -e cores3_linux -t upload` (or the
   poll-and-flash loop if it won't stay up: flash the instant `/dev/ttyACM0`
   appears — esptool resets it into the bootloader where the app can't crash).
3. **Verify:** stable on USB **battery-off** = app itself is stable (= "stabilized
   as it stands"). Then **battery ON** to test against the OCP:
   - holds → the load-spike OCP is mitigated (fix works).
   - still drops out battery-on while rock-stable battery-off → **hardware**
     (pack/connector) fault, not firmware. Swap/RESEAT the DinBase battery.
   - `[TRIP]` fires → read it: which IRQ (`bocp`/`ldooc`/`vrem`), boot vs runtime.

## Environment / gotchas

- Device: `/dev/ttyACM0` on the **Linux laptop** via the **`cores3_linux`** env
  (added for Linux; inherits `cores3`, overrides port). Windows side = COM16 via
  `cores3` (usbipd). ModemManager already ignores the device.
- All `STKCHAN_*` diag flags are **0** (committed `e5a25f1`); the diag scaffold
  (bare path, `DiagTlsStreamSource`, telemetry) is dormant but has a **latent
  double-free** in its fetch-failure teardown — fix that before re-enabling diag.
- lobsterboy diag HTTP/HTTPS servers (`:8088`/`:8443`) are torn down.
- Bisection rung commits 2c–2e + telemetry + restore are on `feat/presence-awareness`
  (2c/2d were also on `main` earlier). `git log` tells the full story.

## Methodological note

Six clean isolation rungs were the signal that the *test setup*, not the
subsystems, was wrong — the battery wasn't in the discharge path. Power telemetry
(vbat/vbus + AXP regs) is what cracked it. The real app, run under that telemetry,
is what finally reproduced the fault. Don't trust a "clear" without confirming the
battery is actually in the discharge path and reading how close to the OCP it got.

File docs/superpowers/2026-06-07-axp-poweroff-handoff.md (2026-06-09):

> **⛔ SUPERSEDED (2026-06-09) — root cause FOUND & FIXED.** The silent AXP power-off is an
> **I2C-controller collision**, not a current/load/PCM problem. `Servos::begin()` does
> `Wire1.begin(17,18,400k)` = `I2C_NUM_1`, the SAME controller M5Unified uses for the
> internal AXP2101 bus (0x34, ES7210 0x40, touch 0x38, AW9523B 0x58) → a stray write disables
> a core rail → silent SoC off; the AXP holds the bad register state → battery-pull recovery.
> Source-confirmed (`M5Unified.cpp:1620-1631`) and empirically proven (an empty Port C scan
> returned the internal constellation). **Everything below about a current-spike /
> battery-PCM-OCP trip and "reduce firmware peak current" is VOID.** Fix shipped in
> `src/hal/Servos.cpp` (PCA9685 moved off `Wire1`/I2C_NUM_1 → `Wire`/I2C_NUM_0, same pins).
> Canonical record: the `axp-brownout-state` memory. Kept below for the historical
> elimination trail only.

# AXP power-off — investigation handoff (2026-06-07)

Branch: `diag/axp-silent-poweroff` (off `feat/presence-awareness`). Supersedes the
2026-06-06 handoff. Pair with the `axp-brownout-state` memory and the gated debug
plan in `2026-06-07-axp-poweroff-debug-plan.md`.

## TL;DR

The device powers off on its own. After a long session that **invalidated most prior
timing data** (a laptop-sleep confound) and reframed the bug twice, the current best
understanding:

- There appear to be **two faces of the failure**, both presenting as a **silent SoC
  power-off with vbat HEALTHY (~4.15 V) and zero AXP fault** (not the "vbat collapses
  4.15→0" the 2026-06-06 handoff assumed):
  - **Bug A — idle, battery+USB:** silent off at **~30 min** (clean, sleep-inhibited).
    Unit #2 ran **>1 h idle** without it → leans **unit-#1-specific** (n=1 each).
  - **Bug B — load-triggered, battery-only (the production-relevant one):** crashes
    **during a TTS "say"** (web control or voice). Reproduced on unit #1 across **two
    different batteries (incl. no DinBase)**. Recovery needs a **battery pull**.
- **Root cause NOT yet proven.** Leading hypothesis for Bug B: a **fast (<100 ms)
  current spike** from the streaming-TTS overlap (WiFi-RX download + amp playback) trips
  the **battery pack's own protection (PCM)** — NOT the AXP. Strong circumstantial
  support; not confirmed by a current measurement.

## The two big course-corrections this session (don't re-learn these)

1. **⚠️ LAPTOP-SLEEP CONFOUND (the big one).** The laptop's
   `gsettings ... sleep-inactive-{ac,battery}-type` was `'suspend'` → on idle it
   powered down the USB bus → dropped `/dev/ttyACM*` → my capture recorded that as a
   "device death" AND froze the capture. This **falsified** the "deconfound dies in 15 s"
   result and means **every earlier session timing** (batteryless ~139 s, battery+USB
   6–16 min, SOAK_MINIMAL 7.6 min, "deaths within seconds") is **sleep-contaminated —
   do not trust.** FIX (done, permanent): gsettings set to `'nothing'`. Also always wrap
   soaks in `systemd-inhibit --what=idle:sleep --mode=block`. *Survivals* with continuous
   heartbeats (bare 54–60 min, output_power/network/M5.update eliminations) are still
   valid — a sleep would have dropped the port mid-stream.

2. **Signature is "vbat healthy → silent cut," NOT "vbat collapse."** Measured on both
   battery+USB (Bug A) and battery-only (Bug B). The production "collapse" was likely a
   dying-ADC artifact, or a different mode. The AXP registers (0x00/0x01, IRQ 0x48-0x4A)
   never change at the cut.

## The decisive measurement (Bug B), via SD logging

Battery-only has no live USB serial, so we logged the `[AXPT]` trail to **microSD** with a
flush per sample; on the next boot the firmware dumps the prior run's log over USB. The
captured battery-only crash trail (`2026-06-07-unit1-batteryonly-crash-trail.txt`):

- 369 samples, `up=2882 → 44540 ms`; **vbat 4092–4159 mV the ENTIRE time (never sagged);
  vbus=0 (battery-only); AXP regs constant; then INSTANT cut.**
- → **Not a gradual brownout.** Consistent with a **sub-100 ms current spike** the 100 ms
  sampling can't see (vbat is a voltage proxy; **CoreS3 has no battery-current ADC** —
  getBatteryCurrent/getVBUSCurrent are hardwired 0). A faster vbat sampler was built
  (100 Hz) but **never flashed/tested** (see "what blocked").

## Recovery signature → points at the battery PCM, not the AXP

Battery-only, after a crash: **power button does NOT restart it — only pulling the
battery does.** Reasoning: battery-only → when the PCM cuts the cell, the AXP loses its
only input → unpowered → PWRON dead → reseating the battery resets the PCM. A plain AXP
soft-off (reg 0x10) would be PWRON-recoverable; it isn't. Matches `ecf953b`'s "tripped the
PACK's own protection," now across two batteries. CONSEQUENCE: can't change the battery's
PCM → **the fix must be a firmware PEAK-CURRENT reduction** (and the AXP-latch read is moot
— the battery pull wipes the AXP always-on domain anyway).

## Ruled out (measured this session)

Hardware-as-dead (bare-WiFi ran 54–60 min; both units run), AXP internal OCP/thermal, I2C
corruption (cid 0x03 = 0x4A always), I2C "shark-fin" artifact, firmware-crash (HWCDC
survives resets; full power loss seen), battery-path OPEN as the cause, `output_power`
(bare survived 60 min with it false), the always-on network stack (full app + SOAK_MINIMAL
still died), `M5.update()`/power-button path (bare + M5.update survived 60 min), the
`bf4b46b` `0x16` ilim write (removing it didn't stop deaths). **Gate 0 code read:** the
firmware does **NO power manipulation** — only the (disabled) `0x16` write; zero GPIO
writes; every `M5.Power.*` call is a READ; no powerOff/sleep/timerSleep anywhere. So the
off is **not commanded by our code** → load/electrical or hardware.

## Hardware / unit state

- **Unit #1** (MAC `10:20:BA:26:E8:98`): the abused test unit. Reproduces Bug A (idle
  ~30 min, battery+USB) and Bug B (load crash, battery-only). Its flash got **corrupted**
  by repeated abrupt power-cuts + esptool churn → boot loop (`rst:0x3 RTC_SW_SYS_RST`);
  **recovered** by reflashing the known-good build. Currently runs **known-good `2195962`
  firmware (no SD logger)**, USB-only at last check (no battery → vbat reads floating ~0,
  expected).
- **Unit #2 / "Jarvis"** (MAC `F4:12:FA:BA:0E:04`): 2nd CoreS3, was running other firmware
  ("Jarvis"); we **backed it up** (`/home/jarod7736/jarvis_full_backup.bin`, 16 MB,
  byte-exact restore) and flashed our deconfound build. Ran **>1 h idle** (didn't repro
  Bug A). Its USB serial is unreliable (re-enumerates ~every 75–140 s → HWCDC drops TX) —
  a unit-specific USB quirk. **Restore Jarvis from the backup when done with it.**
- **USB gotcha:** the original laptop port went flaky (re-enumeration storms, esptool I/O
  errors) — a **different port (1-3) is stable**. Node hops `ttyACM0↔ttyACM1`; tools glob
  `/dev/ttyACM*`. The flakiness was the *port*, not (only) the device.

## Git / firmware / artifact state

- **Branch:** `diag/axp-silent-poweroff` (pushed to origin). HEAD `2195962` = the
  known-good `[AXPT]` build (no SD), which is **what's flashed on unit #1**.
- **Stashed:** `stash@{0}` = the **SD crash-trail logger + 100 Hz vbat sampler**
  (`src/main.cpp` only). Restore with `git checkout diag/axp-silent-poweroff &&
  git stash pop`. NOTE: the SD logger WORKS (captured the trail) but **repeated
  crash-testing with it corrupts the device flash** — harden it (or use a fresh card /
  external scope) before heavy reuse.
- **Uncommitted (working tree):** `tools/fast-flash.sh` (now globs ttyACM*),
  `tools/loop-capture.sh` (NEW, survives re-enumeration), `tools/presence-monitor.sh`
  (NEW, death-by-sustained-USB-loss), and two docs (this plan/handoff + the crash-trail).
- **Evidence:** `2026-06-07-batteryless-usb-stable-openpin-signature.log` (batteryless
  open-pin signature), `2026-06-07-unit1-batteryonly-crash-trail.txt` (the Bug B trail).
- **Tools:** `fast-flash.sh` (catch port + direct esptool), `fast-capture.sh` (single-shot),
  `loop-capture.sh` (looping, re-enum-proof), `presence-monitor.sh`. Always run captures
  under `systemd-inhibit --what=idle:sleep --mode=block`.

## What blocked us at the end (so you don't repeat it)

- Trying to flash the 100 Hz build, my **back-to-back esptool retries** (each toggles the
  reset line) + the flaky port drove a re-enumeration storm and left unit #1 stuck/looping;
  combined with crash-corrupted flash → it wouldn't boot. **Lesson: ONE clean flash, on the
  stable port; don't loop esptool.** Recovery = reflash known-good on the stable port.

## Resume plan (gated — see the debug-plan doc for the full tree)

Pick by what you want to confirm, sleep always inhibited:

1. **Confirm Bug B mechanism without stressing the device flash → external multimeter/scope
   on the battery during a "web say."** Directly shows the current spike / sag at the trip.
   This is the *definitive* test and avoids the SD-corruption problem. **Recommended.**
2. **Or** restore the SD logger (stash pop), reformat the card, reflash unit #1, and re-run
   battery-only "web say" with the **100 Hz** vbat sampler — to see if any sag appears in
   the final ms (voltage event) vs flat (current trip). Caveat: a current trip won't sag
   vbat at any rate; and crash-testing re-corrupts flash.
3. **Then the FIX (once mechanism confirmed):** reduce the firmware's peak current on
   battery — de-overlap WiFi-download and amp (buffer-then-play, reverses the streaming
   decision in `audio-streaming-decision`), OR a streaming-compatible cut (lower volume
   and/or throttle WiFi-RX during playback). Test: battery-only "web say" survives.
4. **Bug A (lower priority):** if it matters, re-confirm the idle ~30 min battery+USB death
   on unit #1 vs unit #2, sleep-inhibited, to settle unit-specific-hardware vs firmware.

## Interaction model reminder (for testing)

Voice is **press-and-hold the screen** (touchscreen `g_pressFlag`), speak, release — no
wake word. Needs WiFi + reachable STT/chat/TTS backends (else "sleepy"/"doubt" error face).
The **web control page** (`http://<ip>/`, unit #1 was `192.168.1.121`, SSID `holdfast`) can
send a "say <text>" → TTS playback — the cleanest Bug B trigger. Backends confirmed working
(saw an LLM reply this session).

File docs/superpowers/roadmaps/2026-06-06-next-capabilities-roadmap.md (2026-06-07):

# Stack-chan — Next Capabilities Roadmap

**Date:** 2026-06-06
**Status:** Roadmap (sequencing + decision-points only — each capability gets its own spec → plan → build cycle)
**Supersedes:** the Phase 3+ bullets in [`../specs/2026-06-02-stackchan-design.md`](../specs/2026-06-02-stackchan-design.md) §11

---

## Context

v1 is ~95% built (touch-to-talk → Whisper STT → Ollama/`oc-personal` chat → cloud TTS,
LVGL avatar face, 2-DOF servo motion, WiFi/web-UI/OTA). The owner wants to plan three
new capabilities, in stated priority:

1. **Face recognition / presence**
2. **Agent / MCP tools**
3. **Wake-word / hands-free**

This document sequences them, names what already exists (so we evolve rather than
rebuild), and flags the decisions each future spec must resolve. It deliberately stays
at roadmap altitude — no implementation detail.

### Planning assumption: the brownout is fixed

The device is currently dark for power debugging — every soak flag in `src/config.h` is set
(`STKCHAN_SOAK_MINIMAL`, `STKCHAN_BARE_WIFI`, `STKCHAN_BARE_AUDIO`, `STKCHAN_AUDIO_PLAYBACK`,
`STKCHAN_AUDIO_DECODE` = 1) while the AXP2101 brownout is bisected. **For this roadmap we
assume that work lands first**: the soak flags go back to 0 and the full app (FSM, face,
audio, servos, probe) runs with power margin. That removes power as the sequencing driver,
so the three capabilities order by **value + dependency**, matching the owner's stated
priority.

Power doesn't vanish from the picture, though — it drops from a *gate* to a *validation
item* on the one feature that adds steady-state load: wake-word's continuous mic (see
Track C). Everything else is server-side or a light HTTP poll.

---

## What already exists (don't rebuild)

| Seam | Where | Implication |
|---|---|---|
| **Agent backend** | `src/net/ChatClient.cpp:73-122` — `send(..., brainMode)` routes to a second host (`brain_host`) as a one-shot to model `oc-personal` with `Bearer brain_key`; the agent owns its own tools + context server-side. | Agent/MCP is **evolution, not a graft**. The spec's risk R2 ("gemma3n lacks tool support blocks MCP") is **moot** — tools never run on the casual model. |
| **Event injection into the FSM** | `src/app/ControlBridge.{h,cpp}` — thread-safe queue: `pushExpression / pushServo / pushVolume / pushSay`, drained on the main loop. `SAY` → `requestExternalSpeak()` (IDLE-guarded). | Presence proactive actions ride ControlBridge. **Bug to fix:** `EXPRESSION`/`SERVO` dispatch *unconditionally* (`ControlBridge.cpp:68-80`) — a presence cue mid-turn would stomp the active face. Gate non-speech pushes on `currentState()==IDLE`. |
| **Background work during long waits** | `state_machine.cpp:67` chat task pinned to core 0; idle motion kept alive during the wait; one "checking…"/doubt cue for brain routes (`:195-198`). | Agent latency UX is *partially built* — the gap is *progressive* feedback over 5–30 s, an enhancement not a from-scratch build. |
| **HTTP poll pattern** | `src/net/ConnectivityTier.cpp:17-25` — simple time-gated 30 s probe, IDLE-only. | Replicate this 3-line pattern for the presence poll; **don't** abstract a shared poller (gating differs per consumer — low value). |

**NVS note:** the 15-char limit is per-key, not a key-count cap. `vision_url`, `owner_name`,
`wake_word`, `kws_model`, `wake_thresh` all fit. Note it; it won't shape design.

---

## The roadmap

Three features, ordered by the owner's priority (power no longer reorders them). They are
mutually independent — no feature blocks another — so the sequence is about focus, not hard
dependency. Each large feature splits into a **server-side** piece (startable independently)
and a **device-side** piece.

```
Phase 1  Face recognition / presence
           1a  stackchan-vision service on lobsterboy   (server; the long pole)
           1b  VisionClient + PresenceManager            (device; needs 1a)

Phase 2  Agent / MCP tools
           2a  confirm oc-personal session capability    (server question)
           2b  routing + multi-turn + latency UX         (device; evolves the seam)

Phase 3  Wake-word / hands-free
           3a  hardware-fork decision                    (on-chip KWS vs LLM Module)
           3b  continuous-capture path + onWakeDetected  (device; validate power load)
```

### Phase 1 — Face recognition / presence (owner's #1)

**1a — `stackchan-vision` service (server, the long pole).** Pure work on `lobsterboy`; no
device dependency. This is the bulk of the feature and can start independently of everything
else.
- Build/deploy the Python systemd unit (Appendix A): `GET /presence` →
  `{seen, confidence, since_ms}`, `GET /healthz`. Camera = USB webcam or RTSP/MJPEG URL
  (server-side — no on-device camera, no second device).
- Enrollment flow for the owner's face; privacy posture per Appendix A (labels + confidence
  only off-box; no frames; snapshot off by default — already sound, keep it).
- **Decision-points:** recognizer (`face_recognition`/dlib vs InsightFace if accuracy
  disappoints); camera source (USB vs IP cam).

**1b — VisionClient + PresenceManager (device, needs 1a).**
- `net/VisionClient`: IDLE-only poll of `/presence`, short-circuit when `tier != LAN_OK`
  (copy the `ConnectivityTier` poll pattern).
- `PresenceManager`: debounce/hysteresis (arrived ≥3 s / left ≥30 s / unknown ≥10 s) +
  greeting-suppression (<10 min); proactive cues via ControlBridge **with the IDLE-gating
  fix** (greet on arrival, sleepy on departure, tilt at unknown).
- **Decision — poll interval:** Appendix A's 2 s is 15× the 30 s tier probe. Mostly a
  network-cost choice now that power has margin; 5–10 s (or piggyback on the tier probe) is
  still likely plenty for presence and cheaper.
- **Decision:** where debounce + greeting-suppression state lives (net-new, no home today).

### Phase 2 — Agent conversations: streaming + follow-up memory

Evolve the existing `brainMode`→`oc-personal` seam (it already routes to server-side tools —
evolution, not a graft). **Designed in detail** — see the plan; scoped to the two things the
owner flagged: the dead 5–30 s wait and no follow-ups. (Routing accuracy and raw-reply
quality were explicitly left out of scope.)

- **2a — Streaming pipeline (the latency fix), DECIDED: unified.** Both casual *and* agent
  replies stream through one pipeline: LLM streams tokens → device segments sentences → TTS
  per sentence → a 2-deep audio queue plays sentence-by-sentence while the next generates.
  Cuts time-to-first-audio to *(first sentence + its TTS)*. One interleaved core-0 task keeps
  a single TLS session live at a time (chat *or* TTS), using TCP backpressure to hold the LLM
  at sentence boundaries. **Buffer-then-play is retired** ([[audio-streaming-decision]]); the
  power overlap this re-introduces is acceptable — **rung 2e cleared 30 min clean on
  battery**. Persona format changes to `<expr>` *before* `<speech>` so the face is set before
  speech streams. New host-tested `StreamParser`; new `AudioQueue`; new `STREAMING` FSM state.
- **2b — Hybrid follow-up memory (the follow-ups fix), DECIDED.** RAM `session_id` sent to
  `oc-personal` + a small device-side replay-ring fallback + a ~90 s sticky conversation
  window so "what about Friday?" continues the thread without keyword routing.
- **2c — Server contract (oc-personal, out of this repo):** SSE un-chunked streaming
  (`stream:true`, `data: … [DONE]`); honor `session_id` with a TTL; *optionally* adopt the
  `<expr>`-first format so agent replies can drive expression (else agent stays neutral-faced).

### Phase 3 — Wake-word / hands-free

The only feature adding **steady-state device load** (continuous mic). With the brownout
assumed fixed this is no longer *gated* on power, but the continuous-mic draw must be
**validated against the repaired power budget** before committing to the on-chip path.
- **3a — hardware fork (the major branch):** on-CoreS3 KWS (ESP-SR / microWakeWord — RAM/CPU
  budget + continuous-mic current) vs. the ~$50 M5 LLM Module. Note: spec §4 *excludes*
  Port C UART / M5Bus, so the LLM Module is a **BOM + hardware-policy change**, not a
  drop-in accessory.
- **3b — Design problem, capture coexistence:** spec §6 invariant 3 ("TTS and mic never
  overlap") + `MicRecorder` is press-and-hold only. Continuous KWS needs a *separate*
  always-on capture path that coexists with the press-and-hold recorder and yields the I²S
  mic during TTS.
- **3b — New FSM edge:** IDLE→LISTENING via a new `onWakeDetected()` trigger (analogous to
  `onPressDown()`). This is the one genuinely new FSM entry point — ControlBridge can't
  express "start a turn."

---

## Synergies (note, don't scope here)

- **Face recognition × proactive behaviors:** `onOwnerArrived` greeting is the first
  proactive push; a later MQTT/Home-Assistant notifier (spec §11) reuses the same
  ControlBridge `SAY` path.
- **Agent × everything:** once tools work, presence ("who's here?") and proactive
  reminders can be agent-driven rather than hard-coded.

## Corrections to prior framing (captured so they aren't re-litigated)

1. Power is **assumed fixed** for this roadmap, so it no longer reorders the features. The
   one residual power concern is wake-word's continuous mic, demoted from a gate to a
   validation item (Phase 3).
2. "Face recognition has near-zero device power impact" → **overstated even so.** A 2 s poll
   is 15× the existing probe rate; with margin restored it's a network-cost choice, not a
   blocker.
3. "Build a shared event-injection path" → **already exists** (`ControlBridge`); presence
   reuses it, only wake-word needs a small new trigger.
4. Spec §11 / R2 MCP framing is **stale** — the `brainMode`/`oc-personal` seam supersedes it.

## Critical files (for the future per-feature specs)

- `src/config.h` — soak flags (Phase 0 gate), NVS keys, brain seam config, `kErr*` taxonomy
- `src/state_machine.cpp` — FSM, `transcriptWantsBrain` routing, core-0 chat task,
  `requestExternalSpeak`, IDLE-gating point, future `onWakeDetected()`
- `src/app/ControlBridge.{h,cpp}` — shared event queue (presence reuses; EXPRESSION/SERVO
  stomping fix lives here)
- `src/net/ChatClient.cpp` — `brainMode`/`oc-personal` seam (agent evolution + multi-turn)
- `src/net/ConnectivityTier.cpp` — poll pattern to replicate for `VisionClient`

## Next step

Each capability proceeds through its own brainstorm → spec (`docs/superpowers/specs/`) →
plan (`docs/superpowers/plans/`) cycle. Recommended order to *spec next*:
**Phase 1 — Face recognition**, starting with the `stackchan-vision` service (1a), the
long pole and the owner's top priority.

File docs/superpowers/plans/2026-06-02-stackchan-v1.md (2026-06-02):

# Stack-chan v1 Implementation Plan

> **For agentic workers:** REQUIRED SUB-SKILL: Use superpowers:subagent-driven-development (recommended) or superpowers:executing-plans to implement this plan task-by-task. Steps use checkbox (`- [ ]`) syntax for tracking.

**Goal:** Ship the Phase 1 voice-interactive desk companion described in `docs/superpowers/specs/2026-06-02-stackchan-design.md` — touch-to-talk on an M5Stack CoreS3 + Stack-chan servo base, talking to Whisper API → Ollama → cloud TTS, with an animated face and idle head motion.

**Architecture:** Single-threaded Arduino-ESP32 FSM (Jarvis's pattern). Device orchestrates the whole turn; lobsterboy hosts Ollama only. Modules separated by responsibility: `hal/` (audio, mic, servos, display), `face/` + `motion/` (Avatar + servos), `net/` (HTTP clients + connectivity tier), `persona/` (prompt + parser), `services/` (NVS, OTA, captive portal).

**Tech Stack:** PlatformIO + Arduino-ESP32, M5CoreS3, M5Stack-Avatar, ESP8266Audio (MP3 decode), ESPAsyncWebServer (captive portal), ArduinoJson, ServoEasing + Adafruit PCA9685, Unity (native unit tests). Face recognition is **out of scope** for this plan — its design lives in Appendix A of the spec.

---

## Conventions & invariants (read once, apply everywhere)

These come from the spec and Jarvis's PRs; they apply to every task.

1. **FSM owns transitions.** HAL/net callbacks set flags; they never call HAL/net directly or transition state directly.
2. **Render before HTTP.** Anything that should display (Face, status) renders *before* the blocking `http.POST()`.
3. **`http.end()` on every exit path** of every HTTP client. Timeout, parse error, success — all paths.
4. **PSRAM rule.** Any buffer > 512 B uses `ps_malloc` or `DynamicJsonDocument` against PSRAM. Small request bodies stay on stack as `char[256]`.
5. **NVS namespace is `"stkchan"`, keys ≤ 15 chars.**
6. **Errors route through `kErr*` constants in `src/config.h`.** Pattern: `g_state = ERROR` → `face.setExpression(...)` → `tts.synth(kErr*)` → `audio.play()` → `SPEAKING` → `onPlayDone` → `IDLE`. Never silent IDLE.
7. **All commits go through pre-commit hooks** (if any are installed) — never use `--no-verify`.
8. **Commit after every task** so each step is atomic and reviewable.

If a step contradicts these conventions, **stop and ask** — don't silently deviate.

---

## File map (created or modified across tasks)

```
Project-StackChan/
├── platformio.ini                     T1
├── default_16MB.csv                   T1
├── .gitignore                         T1
├── README.md                          T1
├── partitions/                        (none — use root default_16MB.csv)
├── data/web/                          T6 (captive portal UI)
├── src/
│   ├── main.cpp                       T1 (hello), T21 (wired)
│   ├── config.h                       T2
│   ├── state_machine.h                T20
│   ├── state_machine.cpp              T20
│   ├── services/
│   │   ├── NvsStore.h                 T3
│   │   ├── NvsStore.cpp               T3
│   │   ├── OtaService.h               T7
│   │   ├── OtaService.cpp             T7
│   │   ├── CaptivePortal.h            T6
│   │   └── CaptivePortal.cpp          T6
│   ├── net/
│   │   ├── WifiManager.h              T4
│   │   ├── WifiManager.cpp            T4
│   │   ├── ConnectivityTier.h         T5
│   │   ├── ConnectivityTier.cpp       T5
│   │   ├── SttClient.h                T11
│   │   ├── SttClient.cpp              T11
│   │   ├── ChatClient.h               T13
│   │   ├── ChatClient.cpp             T13
│   │   ├── TtsClient.h                T9
│   │   └── TtsClient.cpp              T9
│   ├── hal/
│   │   ├── AudioPlayer.h              T8
│   │   ├── AudioPlayer.cpp            T8
│   │   ├── MicRecorder.h              T10
│   │   ├── MicRecorder.cpp            T10
│   │   ├── Display.h                  T19
│   │   ├── Display.cpp                T19
│   │   ├── Servos.h                   T17
│   │   └── Servos.cpp                 T17
│   ├── face/
│   │   ├── Face.h                     T16
│   │   ├── Face.cpp                   T16
│   │   ├── ExpressionMap.h            T15
│   │   └── ExpressionMap.cpp          T15
│   ├── motion/
│   │   ├── MotionDirector.h           T18
│   │   └── MotionDirector.cpp         T18
│   ├── persona/
│   │   ├── SystemPrompt.h             T14
│   │   ├── ResponseParser.h           T12
│   │   └── ResponseParser.cpp         T12
│   └── prompts/
│       └── persona_examples.h         T14
├── test/
│   ├── test_response_parser/          T12
│   │   └── test_response_parser.cpp
│   └── test_expression_map/           T15
│       └── test_expression_map.cpp
└── tools/
    └── provision-stackchan.py         T22
```

---

## Task 1: Repo bootstrap

**Files:**
- Create: `platformio.ini`
- Create: `default_16MB.csv`
- Create: `.gitignore`
- Create: `README.md`
- Create: `src/main.cpp`

**Goal:** A repo that builds, boots on a CoreS3, prints a banner over serial, and commits cleanly.

- [ ] **Step 1: Create `.gitignore`**

```gitignore
.pio/
.vscode/
*.bin
*.elf
*.map
*.swp
*.swo
.DS_Store
__pycache__/
*.pyc
.venv/
node_modules/
```

- [ ] **Step 2: Create `platformio.ini`**

Use Jarvis's known-good PSRAM init (`memory_type = qio_qspi`, **not** the older `flash_mode`/`psram_type` pair the spec mentions). Keep it tight — no Phase-2 libs yet.

```ini
; Project Stack-chan — M5Stack CoreS3 + Stack-chan servo base
; Spec: docs/superpowers/specs/2026-06-02-stackchan-design.md

[platformio]
default_envs = cores3

[env:cores3]
platform = espressif32@6.13.0
board = m5stack-cores3
framework = arduino

; CoreS3 has 8 MB Quad-SPI PSRAM (NOT Octal). qio_qspi is the working
; setting that survives the 3.20017 framework toolchain bump; qio_opi
; leaves ESP.getPsramSize() == 0 and breaks cloud-TTS MP3 allocation.
board_build.arduino.memory_type = qio_qspi

build_flags =
    -DBOARD_HAS_PSRAM
    -DARDUINO_USB_CDC_ON_BOOT=1
    -DCORE_DEBUG_LEVEL=3
    -std=gnu++17

build_unflags =
    -std=gnu++11

board_build.filesystem = littlefs
board_build.partitions = default_16MB.csv

monitor_speed = 115200
monitor_filters =
    esp32_exception_decoder
    time

lib_deps =
    m5stack/M5CoreS3@^1.0.1
    bblanchon/ArduinoJson@^7.2.0
    earlephilhower/ESP8266Audio@^1.9.7
    esp32async/ESPAsyncWebServer@^3.6.0
    esp32async/AsyncTCP@^3.2.0
    meganetaaan/M5Stack-Avatar@^0.10.0
    arduino-libraries/Servo@^1.2.2
    adafruit/Adafruit PWM Servo Driver Library@^3.0.2

; Native unit-test environment (host-side parser/mapper tests). Hardware
; tasks verify on the device; pure-logic modules are TDD'd here.
[env:native]
platform = native
build_flags = -std=gnu++17 -DUNIT_TEST
test_framework = unity
```

- [ ] **Step 3: Create `default_16MB.csv` partition table**

Copy verbatim from Jarvis: `/home/jarod7736/workspace/Project-Jarvis/default_16MB.csv`.

```bash
cp /home/jarod7736/workspace/Project-Jarvis/default_16MB.csv \
   /home/jarod7736/workspace/Project-StackChan/default_16MB.csv
```

If that file doesn't exist (it should — `pio run` in Jarvis succeeds with it), use this standard 16 MB OTA layout:

```csv
# Name,   Type, SubType, Offset,  Size, Flags
nvs,      data, nvs,     0x9000,  0x5000,
otadata,  data, ota,     0xe000,  0x2000,
app0,     app,  ota_0,   0x10000, 0x600000,
app1,     app,  ota_1,   ,        0x600000,
spiffs,   data, spiffs,  ,        0x3F0000,
```

- [ ] **Step 4: Create stub `src/main.cpp`**

```cpp
// Stack-chan v1 — entry point.
// See docs/superpowers/specs/2026-06-02-stackchan-design.md
#include <Arduino.h>
#include <M5CoreS3.h>

void setup() {
  auto cfg = M5.config();
  M5.begin(cfg);
  Serial.begin(115200);
  delay(200);
  Serial.println();
  Serial.println("=== Stack-chan v1 boot ===");
  Serial.printf("PSRAM: %u bytes\n", (unsigned)ESP.getPsramSize());
  Serial.printf("Free heap: %u bytes\n", (unsigned)ESP.getFreeHeap());
}

void loop() {
  M5.update();
  delay(10);
}
```

- [ ] **Step 5: Create minimal `README.md`**

```markdown
# Project Stack-chan

Voice-interactive M5Stack CoreS3 desk companion. See
[`docs/superpowers/specs/2026-06-02-stackchan-design.md`](docs/superpowers/specs/2026-06-02-stackchan-design.md)
for the full design and
[`docs/superpowers/plans/2026-06-02-stackchan-v1.md`](docs/superpowers/plans/2026-06-02-stackchan-v1.md)
for the v1 implementation plan.

## Build

```
pio run                 # firmware
pio run -t upload       # flash via USB
pio run -t uploadfs     # captive-portal UI to LittleFS
pio test -e native      # host-side unit tests
```
```

- [ ] **Step 6: Build to verify the toolchain is happy**

```bash
cd /home/jarod7736/workspace/Project-StackChan
pio run
```

Expected: build succeeds. If a library version doesn't resolve, downgrade to the closest tagged release.

- [ ] **Step 7: Commit**

```bash
git add platformio.ini default_16MB.csv .gitignore README.md src/main.cpp
git commit -m "chore: bootstrap PlatformIO project for Stack-chan v1"
```

---

## Task 2: `config.h` — error taxonomy, timeouts, NVS keys

**Files:**
- Create: `src/config.h`

**Goal:** Single place that downstream modules pull constants from. Spec Section 6 error table, Section 10 NVS keys.

- [ ] **Step 1: Write `src/config.h`**

```cpp
#pragma once
// Stack-chan v1 — global constants.
// See spec section 6 (errors) and section 10 (NVS schema).

#include <stdint.h>

namespace stkchan {

// === NVS ===
constexpr const char* kNvsNamespace = "stkchan";  // keys must be <= 15 chars

constexpr const char* kNvsSsid1     = "ssid1";
constexpr const char* kNvsPsk1      = "psk1";
constexpr const char* kNvsSsid2     = "ssid2";
constexpr const char* kNvsPsk2      = "psk2";
constexpr const char* kNvsSsid3     = "ssid3";
constexpr const char* kNvsPsk3      = "psk3";
constexpr const char* kNvsChatHost  = "chat_host";
constexpr const char* kNvsChatModel = "chat_model";
constexpr const char* kNvsSttUrl    = "stt_url";
constexpr const char* kNvsSttModel  = "stt_model";
constexpr const char* kNvsOaiKey    = "oai_key";
constexpr const char* kNvsTtsProv   = "tts_provider";
constexpr const char* kNvsTtsVoice  = "tts_voice";
constexpr const char* kNvsTtsModel  = "tts_model";
constexpr const char* kNvsElKey     = "el_key";
constexpr const char* kNvsOtaPass   = "ota_pass";
constexpr const char* kNvsPersona   = "persona";

// === Defaults ===
constexpr const char* kDefaultChatModel = "gemma3n:e4b";
constexpr const char* kDefaultSttModel  = "whisper-1";
constexpr const char* kDefaultTtsProv   = "openai";
constexpr const char* kDefaultTtsVoice  = "nova";
constexpr const char* kDefaultTtsModel  = "tts-1";

// === Timeouts (ms) ===
constexpr uint32_t kSttTimeoutMs        = 8000;
constexpr uint32_t kChatTimeoutMs       = 30000;
constexpr uint32_t kTtsTimeoutMs        = 8000;
constexpr uint32_t kTierProbeIntervalMs = 30000;
constexpr uint32_t kMaxRecordMs         = 6000;

// === Audio ===
constexpr uint32_t kRecordSampleRate = 16000;
constexpr size_t   kRecordMaxBytes   = 192 * 1024;  // 6 s @ 16 kHz mono 16-bit
constexpr size_t   kMp3MaxBytes      = 256 * 1024;  // PSRAM cap (PR #55 in Jarvis)

// === Conversation ===
constexpr size_t kHistoryTurns = 6;

// === User-facing error strings ===
// Routed via TtsClient → AudioPlayer; never returned silently.
constexpr const char* kErrNoWifi      = "I can't connect to anything.";
constexpr const char* kErrChatOffline = "My brain's not on the network.";
constexpr const char* kErrMicEmpty    = "Hm, didn't catch that.";
constexpr const char* kErrSttFailed   = "My ears aren't working.";
constexpr const char* kErrChatFailed  = "Brain's stuck, try again.";
constexpr const char* kErrTtsFailed   = "";  // display-only, no speech

}  // namespace stkchan
```

- [ ] **Step 2: Verify it compiles**

```bash
pio run
```

Expected: still builds. `main.cpp` doesn't include `config.h` yet — that's fine.

- [ ] **Step 3: Commit**

```bash
git add src/config.h
git commit -m "feat(config): error taxonomy, timeouts, NVS schema"
```

---

## Task 3: `NvsStore` — cherry-pick from Jarvis

**Files:**
- Create: `src/services/NvsStore.h`
- Create: `src/services/NvsStore.cpp`
- Reference: `/home/jarod7736/workspace/Project-Jarvis/src/app/NVSConfig.h` (Jarvis equivalent)

**Goal:** Tiny wrapper over ESP32 `Preferences` for the `stkchan` namespace. Strings only; everything else uses string-encoded values.

- [ ] **Step 1: Write `src/services/NvsStore.h`**

```cpp
#pragma once
#include <Arduino.h>

namespace stkchan {

class NvsStore {
 public:
  bool begin();   // false if NVS can't be opened
  void end();

  String getString(const char* key, const char* fallback = "");
  bool   putString(const char* key, const String& value);
  bool   eraseKey(const char* key);

  bool hasKey(const char* key);
};

extern NvsStore nvs;  // global singleton

}  // namespace stkchan
```

- [ ] **Step 2: Write `src/services/NvsStore.cpp`**

```cpp
#include "services/NvsStore.h"
#include <Preferences.h>
#include "config.h"

namespace stkchan {

NvsStore nvs;
static Preferences prefs;
static bool g_open = false;

bool NvsStore::begin() {
  if (g_open) return true;
  g_open = prefs.begin(kNvsNamespace, /*readOnly=*/false);
  return g_open;
}

void NvsStore::end() {
  if (g_open) {
    prefs.end();
    g_open = false;
  }
}

String NvsStore::getString(const char* key, const char* fallback) {
  if (!g_open) return String(fallback);
  return prefs.getString(key, fallback);
}

bool NvsStore::putString(const char* key, const String& value) {
  if (!g_open) return false;
  return prefs.putString(key, value.c_str()) > 0;
}

bool NvsStore::eraseKey(const char* key) {
  if (!g_open) return false;
  return prefs.remove(key);
}

bool NvsStore::hasKey(const char* key) {
  if (!g_open) return false;
  return prefs.isKey(key);
}

}  // namespace stkchan
```

- [ ] **Step 3: Wire into `main.cpp` for smoke test**

Append to `setup()` in `src/main.cpp`:

```cpp
#include "services/NvsStore.h"

// ... inside setup(), after Serial.println("=== Stack-chan v1 boot ===");
if (!stkchan::nvs.begin()) {
  Serial.println("WARN: NVS open failed");
} else {
  Serial.printf("NVS chat_host = '%s'\n",
                stkchan::nvs.getString(stkchan::kNvsChatHost, "(unset)").c_str());
}
```

- [ ] **Step 4: Build and flash; verify serial output**

```bash
pio run -t upload && pio device monitor
```

Expected serial: `NVS chat_host = '(unset)'` (or whatever value is in NVS).

- [ ] **Step 5: Commit**

```bash
git add src/services/NvsStore.h src/services/NvsStore.cpp src/main.cpp
git commit -m "feat(nvs): wrapper for stkchan-namespace preferences"
```

---
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

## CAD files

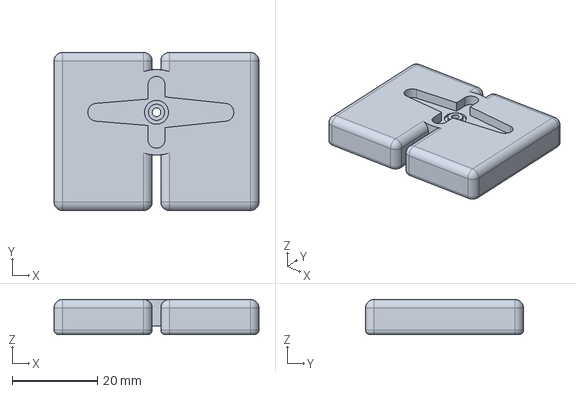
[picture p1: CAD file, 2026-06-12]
hardware/case_SG90/feet_SG90M.step
48.0 x 37.0 x 8.20 mm

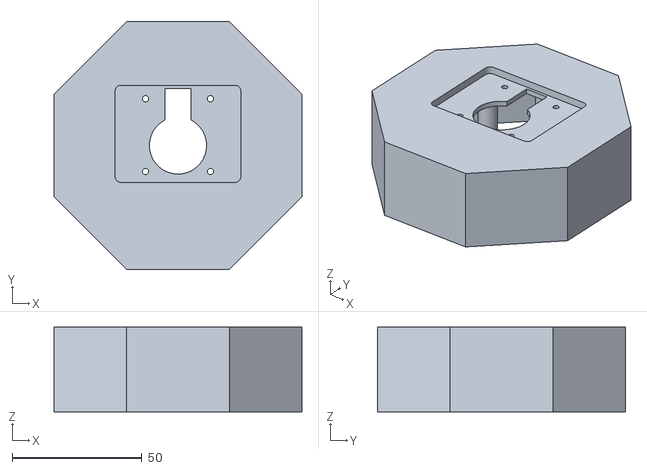
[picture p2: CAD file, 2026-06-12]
hardware/enclosure/pedestal-sg90-body.stl
95.5 x 95.5 x 32.6

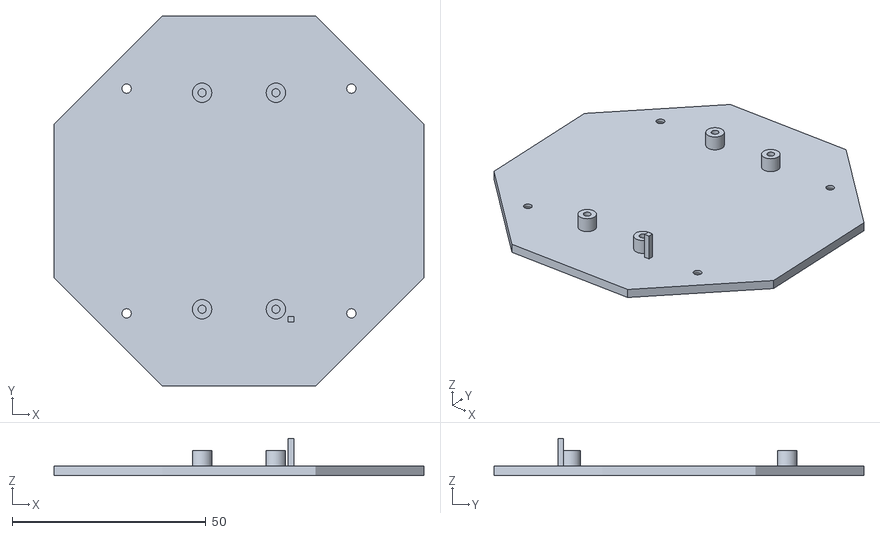
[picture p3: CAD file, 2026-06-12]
hardware/enclosure/pedestal-sg90-bottom.stl
95.5 x 95.5 x 9.60

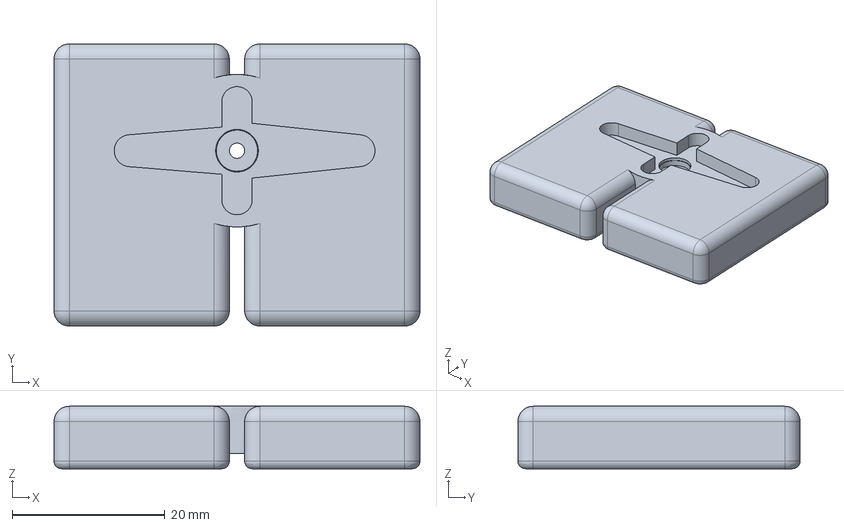
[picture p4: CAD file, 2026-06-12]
hardware/case_SG90/feet_MG90S2.step
48.0 x 37.0 x 8.20 mm

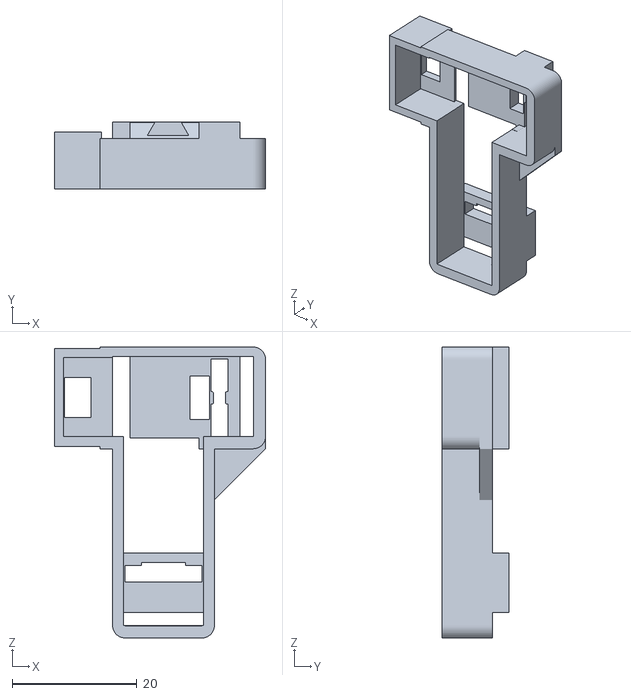
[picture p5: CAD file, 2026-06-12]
hardware/case_SG90/bracket_MG90S2_b.stl
33.8 x 10.7 x 46.6

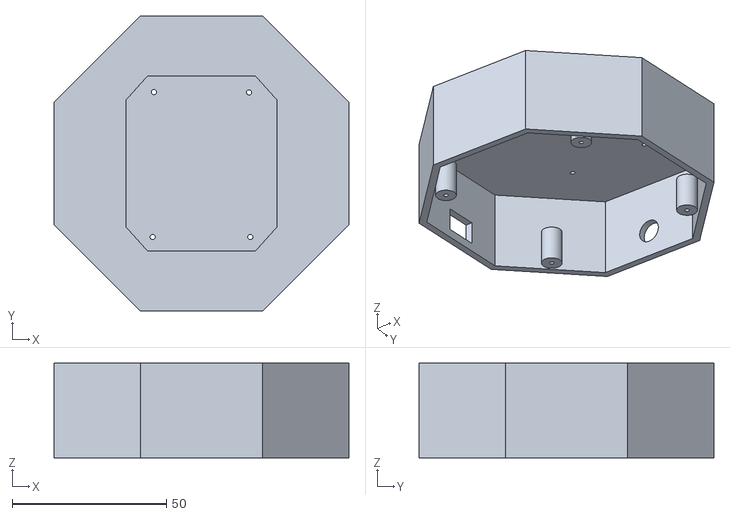
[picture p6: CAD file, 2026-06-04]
hardware/enclosure/pedestal-body.stl
95.5 x 95.5 x 30.6

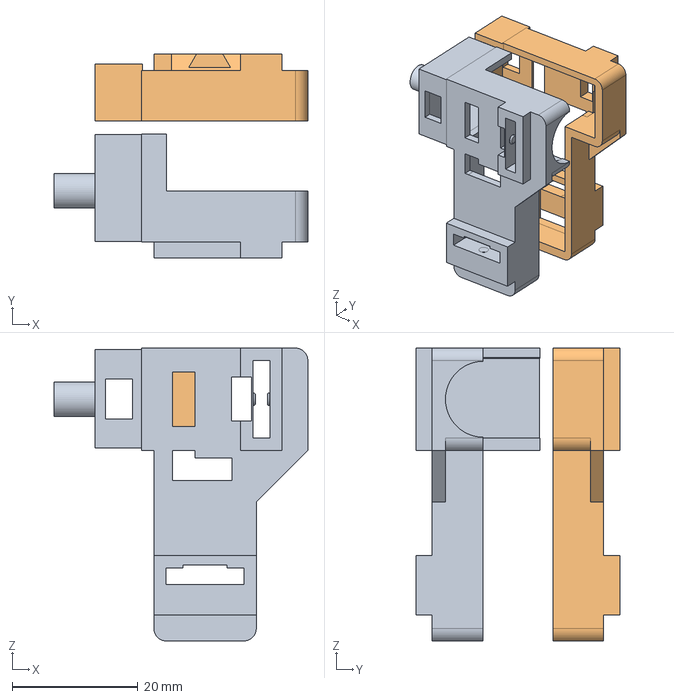
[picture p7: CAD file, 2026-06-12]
hardware/case_SG90/bracket_MG90S2.step
40.4 x 32.4 x 46.6 mm

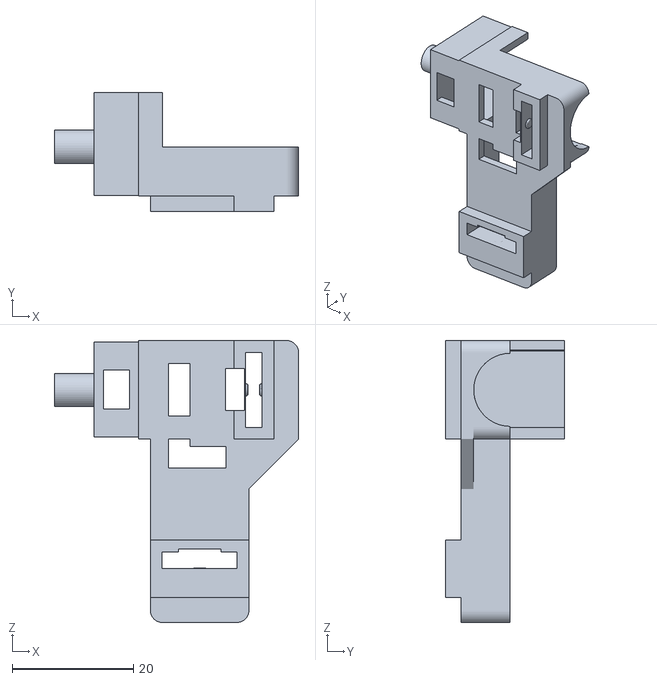
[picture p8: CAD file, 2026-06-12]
hardware/case_SG90/bracket_MG90S2_f.stl
40.4 x 19.7 x 46.6

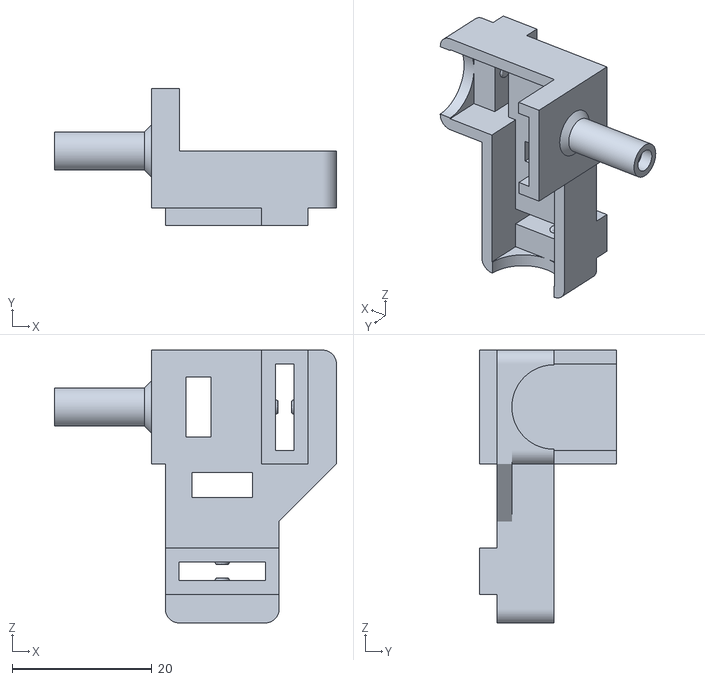
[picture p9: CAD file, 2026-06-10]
hardware/case_SG90/bracket_SG90_f.stl
40.4 x 19.7 x 39.1

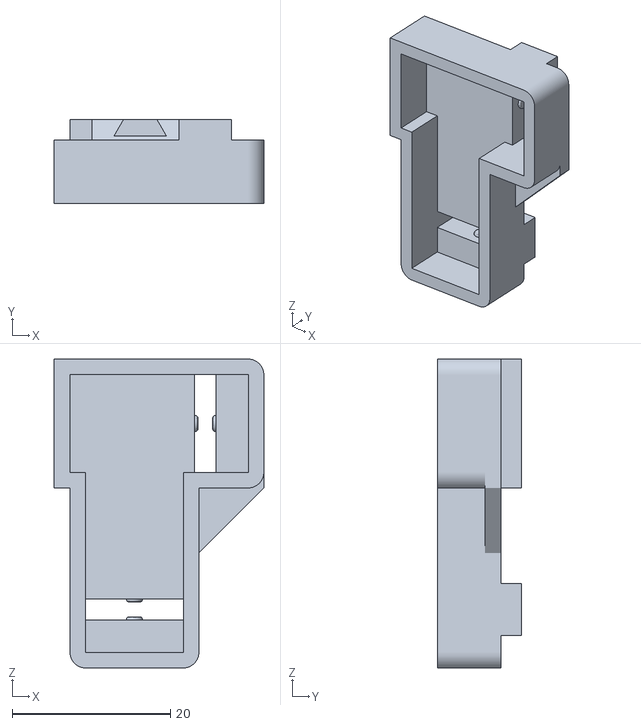
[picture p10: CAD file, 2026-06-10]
hardware/case_SG90/bracket_SG90_b.stl
26.5 x 10.7 x 39.1

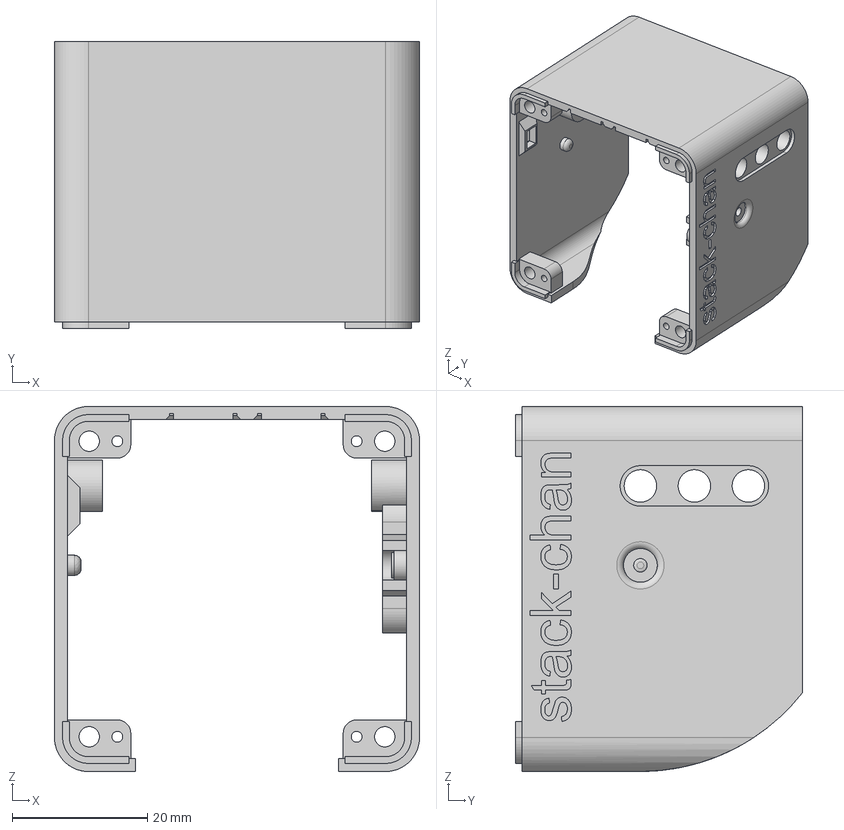
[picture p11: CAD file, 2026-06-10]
hardware/case_SG90/shell_SG90.step
54.0 x 42.5 x 54.0 mm

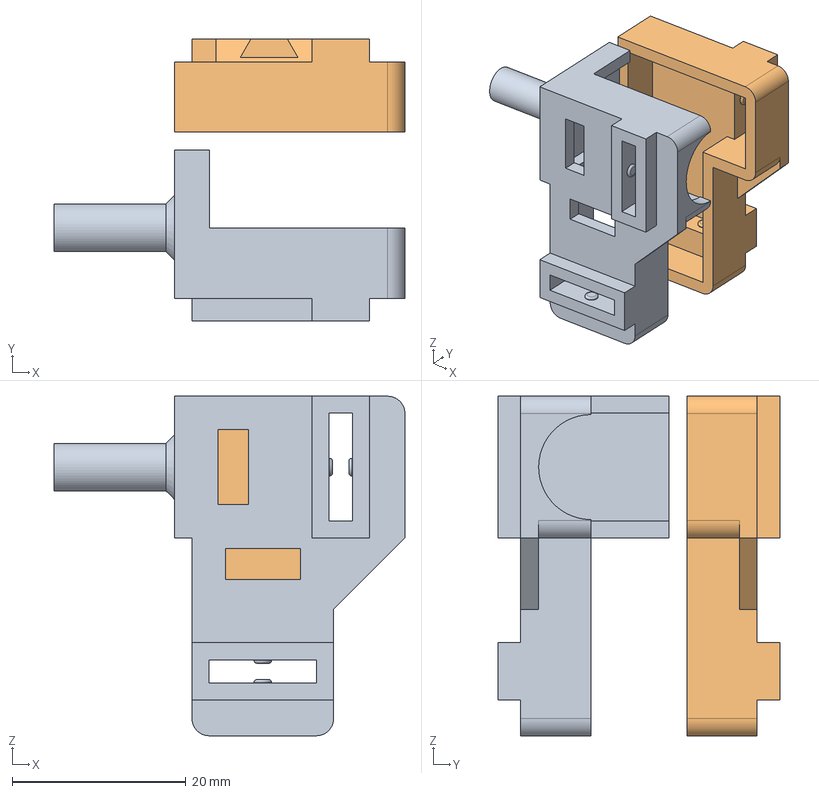
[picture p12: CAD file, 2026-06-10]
hardware/case_SG90/bracket_SG90.step
40.4 x 32.4 x 39.1 mm

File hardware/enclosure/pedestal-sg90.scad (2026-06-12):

// Stack-chan SG90 electronics base  (two-part, removable bottom)
// A stationary base for the SG90 stack-chan: the printed FEET (feet_SG90M,
// 48 x 37 mm, measured from the vendored feet_SG90.step) nest in the top
// recess (rotationally keyed against pan torque) and screw down with 4x M2x8
// driven from inside the cavity; the PCA9685 + barrel jack live inside.
//
// PARTS: set `part` to "body" | "plate" | "both".
//   body  - regular-octagon shell, open bottom, top recess for the feet +
//           center wire pass-through + back wire slot under the feet's cable
//           slot. 4 internal M2 bosses for the plate, 4 feet-screw holes.
//   plate - removable bottom; PCA9685 mounts to its standoffs, then screws
//           up into the body with 4x M2.
// Units: mm.  Origin = center, +Y = back (front of bot faces -Y display side).
//
// FEET ORIENTATION: feet go in rotated 180 deg from their native STEP frame so
// their cable slot exits at the back (+Y, barrel-jack side). The pan-axis hub
// sits at the pedestal origin; the feet bbox center is 4.5 mm behind it, hence
// the asymmetric recess (which also keys the orientation).

part        = "both";

/* ---------- SG90 feet interface (measured from feet_SG90.step) ---------- */
feet_w      = 48.0;     // feet X footprint
feet_d      = 37.0;     // feet Y footprint
feet_clear  = 0.4;      // recess oversize so the printed feet drop in
feet_recess = 3.0;      // how deep the feet nest into the top (keys rotation)
feet_y_off  = 4.5;      // recess center offset behind the hub (feet rot 180)
feet_r      = 2.2;      // recess corner radius (feet corners r2.0 + clearance)
wire_hole_d = 22.0;     // center pass-through for servo cables / horn clearance
/* feet screws: M2x8 pan-head from inside the cavity, through the 2 mm recess
   floor, into 6.5 mm pilot holes in the feet pads (feet_SG90M variant) */
fscrew_pts  = [[12.5,18],[-12.5,18],[12.5,-10],[-12.5,-10]];
/* back wire slot through the recess floor, under the feet's 2 mm cable slot */
fslot_w     = 10.0;  fslot_y0 = 6.0;  fslot_y1 = 22.0;

/* ---------- PCA9685 board + connectors (CONFIRM/measure yours) --------- */
board_along = "Y";
pca_l       = 62.5;  pca_w = 25.4;
pin_over    = 8.0;   hdr_up = 22.0;  pcb_t = 1.6;
mount_dx    = 55.88; mount_dy = 19.05;        // Adafruit/clone hole pattern
standoff_h  = 4.0;   standoff_d = 5.0;  standoff_pilot = 2.1;  // M2.5

/* ---------- Comfort clearances ---------- */
clr_long    = 6.0;   clr_short = 9.0;

/* ---------- Shell ---------- */
/* top_t = recess depth + 2 mm floor (the feet sit on, and screw through, the
   floor; at top_t == feet_recess the recess would be a through-hole) */
wall = 2.5;  top_t = feet_recess + 2.0;  bot_t = 2.5;

/* ---------- Bottom-plate screws (M2) ---------- */
/* bosses run the full cavity height (merge into the top plate) and web into
   the corner chamfer walls — pboss_h is set to in_h in Derived below */
pscrew_xy = 29.0;  pboss_d = 7.0;
pscrew_pilot = 1.6;  pscrew_clear = 2.4;  pscrew_csk = 4.4;

/* ---------- Power: DC barrel jack in back (+Y) wall ---------- */
jack_hole_d = 8.0;  jack_z_off = 4.0;
wire_slot_w = 12;   wire_slot_h = 8;
$fn = 72;

/* ---------- Derived ---------- */
along_y    = (board_along == "Y");
long_need  = pca_l + 2*pin_over + 2*clr_long;
short_need = pca_w + 2*clr_short;
sq    = max(long_need, short_need, feet_w + 8, feet_d + 8);   // square -> regular octagon
in_l  = sq; in_w = sq;
in_h  = standoff_h + pcb_t + hdr_up;
out_l = in_l + 2*wall; out_w = in_w + 2*wall;
H     = in_h + top_t;
pboss_h = in_h;        // boss tops fuse with the top plate
jack_z = standoff_h + pcb_t + jack_z_off;
function reg_cham(s) = s / (2 + sqrt(2));

pscrew_pts = [[pscrew_xy,pscrew_xy],[-pscrew_xy,pscrew_xy],
              [pscrew_xy,-pscrew_xy],[-pscrew_xy,-pscrew_xy]];
m_x = along_y ? mount_dy/2 : mount_dx/2;
m_y = along_y ? mount_dx/2 : mount_dy/2;
mount_pts = [[m_x,m_y],[-m_x,m_y],[m_x,-m_y],[-m_x,-m_y]];

/* ---------- Helpers ---------- */
module octa(w,d,ch,o=0){
  polygon([[-w/2+o,d/2-ch+o],[-w/2+ch+o,d/2-o],[w/2-ch-o,d/2-o],[w/2-o,d/2-ch+o],
           [w/2-o,-d/2+ch-o],[w/2-ch-o,-d/2+o],[-w/2+ch+o,-d/2+o],[-w/2+o,-d/2+ch-o]]);
}
module rrect(l,w,r){ hull() for(sx=[-1,1],sy=[-1,1]) translate([sx*(l/2-r),sy*(w/2-r)]) circle(r=r); }

/* ====================  BODY  ==================== */
module body(){
  union(){
    difference(){
      linear_extrude(H) octa(out_l,out_w,reg_cham(out_l));                          // octagon shell
      translate([0,0,-0.1]) linear_extrude(in_h+0.1) octa(in_l,in_w,reg_cham(in_l)); // cavity, open bottom
      // feet recess in the top (rounded rect; keys the feet against pan torque;
      // offset +Y so the pan-axis hub lands on the pedestal origin)
      translate([0,feet_y_off,H-feet_recess]) linear_extrude(feet_recess+0.2)
        rrect(feet_w+feet_clear, feet_d+feet_clear, feet_r);
      // center wire pass-through for servo cables / horn-screw driver access
      translate([0,0,H-top_t-0.1]) cylinder(d=wire_hole_d, h=top_t+0.2);
      // back wire slot through the recess floor: cables leave the feet's cable
      // slot at the back edge and drop straight into the cavity
      translate([-fslot_w/2,fslot_y0,H-top_t-0.1])
        cube([fslot_w,fslot_y1-fslot_y0,top_t+0.2]);
      // 4 clearance holes for the feet screws (M2x8 driven from inside)
      for(p=fscrew_pts) translate([p[0],p[1],H-top_t-0.1])
        cylinder(d=pscrew_clear,h=top_t+0.2);
      // barrel jack
      translate([0,out_w/2-wall/2,jack_z]) rotate([90,0,0]) cylinder(d=jack_hole_d,h=wall+2,center=true);
      // side wire slot (extra routing)
      translate([-out_l/2-0.6,-wire_slot_w/2,3]) cube([wall+1.2,wire_slot_w,wire_slot_h]);
    }
    // 4 corner bosses for the bottom-plate screws: full cavity height, webbed
    // into the corner chamfer wall (boss edge sits 0.75 mm off it otherwise)
    for(p=pscrew_pts) translate([p[0],p[1],0]) difference(){
      union(){
        cylinder(d=pboss_d,h=pboss_h);
        rotate([0,0,atan2(p[1],p[0])])
          translate([0,-pboss_d/2,0]) cube([6,pboss_d,pboss_h]);
      }
      translate([0,0,-0.1]) cylinder(d=pscrew_pilot,h=pboss_h+0.2);
    }
  }
}

/* ====================  BOTTOM PLATE  ==================== */
module standoffs(){
  for(p=mount_pts) translate([p[0],p[1],0]) difference(){
    cylinder(d=standoff_d,h=standoff_h);
    translate([0,0,-0.1]) cylinder(d=standoff_pilot,h=standoff_h+0.2);
  }
  pl2=pca_l/2; pw2=pca_w/2;
  if (along_y) for(sy=[-1,1]) translate([pw2,sy*pl2,0]) cube([1.5,sy>0?-1.5:1.5,standoff_h+pcb_t+1.5]);
  else         for(sx=[-1,1]) translate([sx*pl2,pw2,0]) cube([sx>0?-1.5:1.5,1.5,standoff_h+pcb_t+1.5]);
}
module plate(){
  difference(){
    linear_extrude(bot_t) octa(out_l,out_w,reg_cham(out_l));
    for(p=pscrew_pts){
      translate([p[0],p[1],-0.1]) cylinder(d=pscrew_clear,h=bot_t+0.2);
      translate([p[0],p[1],-0.01]) cylinder(d1=pscrew_csk,d2=pscrew_clear,h=1.8);
    }
  }
  translate([0,0,bot_t]) standoffs();
}

/* ====================  PLACEMENT  ==================== */
if      (part=="body")  body();
else if (part=="plate") plate();
else { body(); translate([0,0,-bot_t]) plate(); }

echo(str("SG90 BASE octagon ", out_l, " mm across x ", H, " mm | feet recess ",
         feet_w, "x", feet_d, " @ +Y", feet_y_off, " | floor ", top_t-feet_recess,
         " mm | cavity h ", in_h, " mm"));

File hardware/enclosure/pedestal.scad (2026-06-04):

// Stack-chan electronics pedestal  (v3 - two-part, removable bottom)
// Bolts UNDER the existing printed StackChan-Base; the base is the top lid.
// Houses a PCA9685 servo driver + wiring inside a regular-octagon body.
//
// TWO PARTS:
//   body  - regular-octagon shell, OPEN at the bottom, top plate carries the
//           base bolt pattern. 4 internal corner bosses take the bottom screws.
//   plate - removable bottom; the PCA9685 mounts to standoffs on it, then the
//           plate (with board) screws up into the body with 4x M2 screws.
// Set `part` to render/export "body", "plate", or "both" (assembled preview).
// Units: mm.  Origin = center, +Y = back, z=0 = body/plate joint.

part        = "both";   // "body" | "plate" | "both"

/* ---------- Base interface (measured from StackChan-Base.stl) ---------- */
base_w      = 48.0;
base_d      = 56.0;
base_cham   = 7.0;
holes       = [[-15.4,23.1],[15.4,23.0],[-15.8,-23.8],[15.8,-23.8]];

/* ---------- PCA9685 board + connectors (CONFIRM/measure yours) --------- */
board_along = "Y";      // "X" = long edge side-to-side, "Y" = long edge front-to-back
pca_l       = 62.5;     // PCB long edge
pca_w       = 25.4;     // PCB short edge
pin_over    = 8.0;      // pins/terminal overhang on the long end(s)
hdr_up      = 22.0;     // clearance above PCB (20mm board+plugged-servo stack + air)
pcb_t       = 1.6;
// Screw-down mounting (Adafruit PCA9685 pattern: 0.75" x 2.20" = 19.05 x 55.88 mm).
mount_dx    = 55.88;    // hole spacing along PCB long axis
mount_dy    = 19.05;    // hole spacing along PCB short axis
standoff_h  = 4.0;      // board sits this high off the plate
standoff_d  = 5.0;
standoff_pilot = 2.1;   // M2.5 self-tap pilot

/* ---------- Comfort clearances ---------- */
clr_long    = 6.0;
clr_short   = 9.0;

/* ---------- Shell ---------- */
wall        = 2.5;
top_t       = 3.0;      // top plate thickness
bot_t       = 2.5;      // bottom plate thickness
recess_d    = 2.0;      // base nests this deep into the top
boss_d      = 7.5;      // base-bolt boss (in top plate)
boss_pilot  = 1.7;      // M2 self-tap (base bolts)

/* ---------- Bottom-plate screws (M2) ---------- */
pscrew_xy   = 29.0;     // plate screw pos at the 4 diagonal corners (+-xy, +-xy)
pboss_d     = 7.0;      // body corner boss outer dia
pboss_h     = 12.0;     // body corner boss height
pscrew_pilot= 1.6;      // M2 self-tap into body boss
pscrew_clear= 2.4;      // M2 shaft clearance in the plate
pscrew_csk  = 4.4;      // countersink dia on plate underside

/* ---------- Power: panel-mount DC barrel jack in back (+Y) wall ---------- */
jack_hole_d = 8.0;
jack_z_off  = 4.0;
wire_slot_w = 12; wire_slot_h = 8;
$fn         = 72;

/* ---------- Derived sizes ---------- */
along_y    = (board_along == "Y");
long_need  = pca_l + 2*pin_over + 2*clr_long;
short_need = pca_w + 2*clr_short;
// Square footprint -> REGULAR octagon (all 8 sides equal); fits board either way.
sq    = max(long_need, short_need, base_w + 6, base_d + 6);
in_l  = sq; in_w = sq;                       // internal X/Y
in_h  = standoff_h + pcb_t + hdr_up;         // internal height (cavity)
out_l = in_l + 2*wall; out_w = in_w + 2*wall;
H     = in_h + top_t;                        // body height (open bottom, no floor)
jack_z = standoff_h + pcb_t + jack_z_off;    // jack center above the joint
function reg_cham(s) = s / (2 + sqrt(2));

pscrew_pts  = [[pscrew_xy,pscrew_xy],[-pscrew_xy,pscrew_xy],
               [pscrew_xy,-pscrew_xy],[-pscrew_xy,-pscrew_xy]];
m_x = along_y ? mount_dy/2 : mount_dx/2;
m_y = along_y ? mount_dx/2 : mount_dy/2;
mount_pts = [[m_x,m_y],[-m_x,m_y],[m_x,-m_y],[-m_x,-m_y]];

/* ---------- Helpers ---------- */
module octa(w,d,ch,o=0){
  polygon([[-w/2+o,d/2-ch+o],[-w/2+ch+o,d/2-o],[w/2-ch-o,d/2-o],[w/2-o,d/2-ch+o],
           [w/2-o,-d/2+ch-o],[w/2-ch-o,-d/2+o],[-w/2+ch+o,-d/2+o],[-w/2+o,-d/2+ch-o]]);
}

/* ====================  BODY (open bottom)  ==================== */
module body(){
  union(){
    difference(){
      linear_extrude(H) octa(out_l,out_w,reg_cham(out_l));                 // solid octagon
      translate([0,0,-0.1]) linear_extrude(in_h+0.1) octa(in_l,in_w,reg_cham(in_l)); // cavity, open bottom
      translate([0,0,H-recess_d]) linear_extrude(recess_d+0.2) octa(base_w,base_d,base_cham,-0.4); // base recess
      translate([0,out_w/2-wall/2, jack_z]) rotate([90,0,0]) cylinder(d=jack_hole_d,h=wall+2,center=true); // jack
      translate([-out_l/2-0.6,-wire_slot_w/2, 3]) cube([wall+1.2,wire_slot_w,wire_slot_h]);  // wire slot
      for(h=holes) translate([h[0],h[1],H-top_t-0.1]) cylinder(d=boss_pilot,h=top_t+0.2);    // base bolts
    }
    // 4 corner bosses for the bottom-plate screws (merge into the diagonal walls)
    for(p=pscrew_pts) translate([p[0],p[1],0]) difference(){
      cylinder(d=pboss_d,h=pboss_h);
      translate([0,0,-0.1]) cylinder(d=pscrew_pilot,h=pboss_h+0.2);
    }
  }
}

/* ====================  BOTTOM PLATE (removable)  ==================== */
// standoffs built from z=0 (placed on the plate top)
module standoffs(){
  for(p=mount_pts) translate([p[0],p[1],0]) difference(){
    cylinder(d=standoff_d,h=standoff_h);
    translate([0,0,-0.1]) cylinder(d=standoff_pilot,h=standoff_h+0.2);
  }
  pl2=pca_l/2; pw2=pca_w/2;   // anti-rotation nubs along one PCB edge
  if (along_y) for(sy=[-1,1]) translate([pw2,sy*pl2,0]) cube([1.5,sy>0?-1.5:1.5,standoff_h+pcb_t+1.5]);
  else         for(sx=[-1,1]) translate([sx*pl2,pw2,0]) cube([sx>0?-1.5:1.5,1.5,standoff_h+pcb_t+1.5]);
}
module plate(){            // z=0 = bottom (desk) face, standoffs on top
  difference(){
    linear_extrude(bot_t) octa(out_l,out_w,reg_cham(out_l));
    for(p=pscrew_pts){
      translate([p[0],p[1],-0.1]) cylinder(d=pscrew_clear,h=bot_t+0.2);          // shaft clearance
      translate([p[0],p[1],-0.01]) cylinder(d1=pscrew_csk,d2=pscrew_clear,h=1.8);// countersink on underside
    }
  }
  translate([0,0,bot_t]) standoffs();
}

/* ====================  PLACEMENT  ==================== */
if      (part=="body")  body();
else if (part=="plate") plate();
else { body(); translate([0,0,-bot_t]) plate(); }   // assembled preview

echo(str("BODY octagon ", out_l, " mm across x ", H, " mm tall (open bottom) | ",
         "PLATE ", out_l, " mm x ", bot_t, " mm | cavity h ", in_h, " mm"));

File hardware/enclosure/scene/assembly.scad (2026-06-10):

// ===================================================================
//  Stack-chan SG90 (Takao) — illustrated assembly scene
//  Imports the real Takao STLs + simple SG90 / CoreS3 stand-ins and
//  poses them per assembly stage. Drive headless, one PNG per stage:
//    openscad -D 'stage="exploded"' --camera=... -o out.png assembly.scad
//  stages:
//    part_shell | part_bracket | part_feet | part_hat   (single printed part)
//    sg90 | cores3                                       (single stand-in)
//    exploded                                            (all parts pulled apart)
//    step1..step6                                        (build sequence)
// ===================================================================

// stl_dir points at the upstream Takao SG90 STL set (mongonta0716/3DPrinter_Models,
// "stackchan_sg90_case_takao_version"). Not redistributed here — clone it and
// override with -D, e.g.  openscad -D 'stl_dir="/path/to/set"' ...
// tools/render-assembly.sh passes this for you via the STL_DIR env var.
stl_dir = "/home/jarod7736/cloned/stackchan-sg90-models/stackchan_sg90_case_takao_version";
stage   = "exploded";
$fn     = 56;

// ---- palette ----------------------------------------------------------
C_SHELL  = "#9fb8d6";   // head shell (resin grey-blue)
C_BRK    = "#e8927c";   // servo bracket (salmon)
C_FEET   = "#8fd49a";   // base feet (green)
C_HAT    = "#e9d27e";   // cat-ear hat (khaki)
C_SERVO  = "#3a3f4a";   // SG90 body (dark)
C_HORN   = "#e8ecf2";   // servo horn (white)
C_CORE   = "#23262b";   // CoreS3 body (dark)
C_SCREEN = "#39c5d8";   // CoreS3 screen (cyan)

// ---- assembly stack (mm; desk plane at Z=0) --------------------------
// The four STLs are each exported in their own frame; these constants nest
// them into one coherent robot (measured by probing each part).
PAN_XY     = [0, 32];   // pan axis (vertical) at the feet centre hub
FEET_TOP   = 10.6;      // top of feet (pan-horn seat)
PAN_BASE   = 11;        // pan-servo body base, just above the feet
SHELL_DZ   = 17;        // raise the head onto the neck so it clears the feet
HEAD_PIVOT = 8 + SHELL_DZ;   // tilt axis (native shell pivot ~8 + raise)
CORE_Y     = 8;         // CoreS3 screen front plane (just ahead of bracket)
CORE_Z     = SHELL_DZ - 5;   // CoreS3 vertical seat inside the head
BRK_DY     = 15.5;      // bracket Y-shift to match the shell/feet frame

// ======================  PRINTED PARTS (STL)  =========================
module shell()   color(C_SHELL) import(str(stl_dir,"/stackchan_takao_shell_v2_resin.stl"));
module bracket() color(C_BRK)   import(str(stl_dir,"/stackchan_takao_bracket_v2.5.stl"));
module feet()    color(C_FEET)  import(str(stl_dir,"/stackchan_takao_feet.stl"));
module hat()     color(C_HAT)   import(str(stl_dir,"/stackchan_takao_hat_cat_CoreS3.stl"));

// ======================  STAND-INS  ===================================
// 9 g micro servo (this build uses MG90S; SG90/MS18 share the same body class).
// Body 22.8(L,Y) x 12.6(W,X) x 22.5(H,Z); flange at 15.9; output shaft offset
// ~5.9 toward one end. Built shaft-up at local origin, body base at Z=0, shaft on
// +Z, centred on the OUTPUT SHAFT in X/Y. (MG90S is ~1-2 mm longer than SG90.)
module sg90(horn="round") {
    sx = 5.9;                       // shaft offset from body centre (+Y end)
    translate([0, -sx, 0]) {        // shift so shaft lands at local origin
        color(C_SERVO) {
            translate([-6.3, -11.4, 0]) cube([12.6, 22.8, 22.5]);     // body
            translate([-6.3, -16.1, 15.9]) cube([12.6, 32.2, 2.5]);   // mount flange
            translate([0, sx, 22.5]) cylinder(d=4.9, h=4.2);          // boss + shaft
        }
        // wires out the back (-Y)
        for (i=[-1:1]) color(i<0?"#d98a3a":i==0?"#cc3b3b":"#7a4b2b")
            translate([i*2.2, -11.4, 5]) rotate([90,0,0]) cylinder(d=1.4, h=7);
    }
    // horn sits on the shaft (local origin), centred
    color(C_HORN) translate([0,0,26.7]) horn_round();
}
module horn_round() {
    difference() {
        union() { cylinder(d=18, h=1.6); cylinder(d=7, h=3.2); }
        for (a=[0:90:359]) rotate(a) translate([7,0,-0.1]) cylinder(d=1.4, h=2);
        translate([0,0,-0.1]) cylinder(d=2.4, h=4);
    }
}

// M5Stack CoreS3: ~36.5 x 36.5 x 15.5; display on the FRONT face (-Y).
// Built with the front (screen) face on the Y=0 plane, centred X, base Z=0.
module cores3() {
    w=36.5; h=36.5; d=15.5;
    translate([-w/2, 0, 0]) {
        color(C_CORE) cube([w, d, h]);                                // body
        color(C_SCREEN) translate([3, -0.6, 3.2]) cube([w-6, 1.0, h-6.4]); // screen
    }
}

// ======================  PLACEMENTS  =================================
// pan servo: vertical, shaft DOWN into feet hub at PAN_XY
module pan_servo(z=0)
    translate([PAN_XY[0], PAN_XY[1], PAN_BASE + 22.5 + z])
        rotate([180,0,0]) sg90();          // flip so shaft + horn point -Z to feet

// tilt servo: horizontal, body in bracket pocket, shaft -> +X to head pivot
module tilt_servo(dx=0)
    translate([-8 + dx, PAN_XY[1], HEAD_PIVOT])
        rotate([0,90,0]) sg90();           // local +Z (shaft) -> +X

module place_bracket(z=0)
    translate([0, BRK_DY, z]) bracket();   // nest the bracket into the head frame

module place_shell(z=0)
    translate([0, 0, SHELL_DZ + z]) shell();   // raise the head onto the neck

module place_cores3(y=0, z=0)
    translate([0, CORE_Y + y, CORE_Z + z]) cores3();  // screen in the head front

module place_hat(z=0)
    translate([0, 16, (SHELL_DZ - 11.5) + z]) hat();  // seat the hat on the head top

// ======================  STAGE SELECTOR  =============================
if (stage=="part_shell")        shell();
else if (stage=="part_bracket") bracket();
else if (stage=="part_feet")    feet();
else if (stage=="part_hat")     hat();
else if (stage=="sg90")         sg90();
else if (stage=="cores3")       cores3();

else if (stage=="exploded") {
    feet();
    pan_servo(z=24);
    place_bracket(52);
    tilt_servo(dx=34);
    place_shell(z=104);
    place_cores3(y=-46, z=104);
    place_hat(z=92);
}

// build sequence -------------------------------------------------------
else if (stage=="step1") { // centre the servos (show the two SG90s alone)
    translate([-18,32,0]) sg90();
    translate([ 18,32,0]) sg90();
}
else if (stage=="step2") { feet(); pan_servo(); }            // pan servo -> feet
else if (stage=="step3") { feet(); pan_servo(); place_bracket(); tilt_servo(); } // tilt -> bracket
else if (stage=="step4") { feet(); pan_servo(); place_bracket(); tilt_servo(); place_shell(); } // head on
else if (stage=="step5") { feet(); pan_servo(); place_bracket(); tilt_servo(); place_shell(); place_cores3(); } // CoreS3 in
else if (stage=="step6") { feet(); pan_servo(); place_bracket(); tilt_servo(); place_shell(); place_cores3(); place_hat(); } // hat

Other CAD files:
hardware/case_SG90/feet_MG90S2M.step
hardware/enclosure/pedestal-bottom.stl
hardware/case_SG90/feet_SG90.step
hardware/case_SG90/feet_MG90S2.stl
hardware/case_SG90/feet_MG90S2M.stl
hardware/case_SG90/feet_SG90.stl
hardware/case_SG90/feet_SG90M.stl
hardware/case_SG90/shell_SG90.stl

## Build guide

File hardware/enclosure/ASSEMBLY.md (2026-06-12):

# StackChan (MG90S / SG90 · Takao) — Assembly & Fitment Guide

> 📷 Prefer pictures? See the **[Illustrated Assembly guide](ASSEMBLY-ILLUSTRATED.md)**
> — exploded view + a render for every step, generated from the real STLs.
> ⚠️ Its pedestal renders predate the 2026-06 recess rework (the pedestal now
> mates the vendored v1.0 `feet_SG90M`, not the Takao feet shown there).

This is the build we're using: the **"stack-chan_takao_base"** shell (the upstream
"SG90 case" set by Takao Akaki, via `mongonta0716/3DPrinter_Models`), driven by
**MG90S** servos on our CoreS3 + **PCA9685** firmware. It is **not** the M5 K151 shell (that one needs DYNAMIXEL
XL330 serial-bus servos — see "Other design" at the bottom).

## Printed parts (SG90 Takao set)

Source: `mongonta0716/3DPrinter_Models/stackchan_sg90_case_takao_version`
(cloned locally to `~/cloned/stackchan-sg90-models/`).

| STL | Role |
|-----|---|
| `stackchan_takao_shell_v2_resin` | Head shell — wraps the **CoreS3**; speaker grille + "stack-chan" emboss. Display faces front. Rides on the tilt servo. |
| `stackchan_takao_bracket_v2.5` | Servo bracket — holds **both servos** (rectangular pockets): pan (lower) + tilt (upper). |
| `stackchan_takao_feet` | Base feet (54 × 50 × 8 mm) — two pads + a center hub with the **round-horn screw pattern** (shared by MG90S/SG90). The pan servo horn screws here; the body pans on the feet. Central slot routes the servo cables down. |
| `stackchan_takao_hat_cat_CoreS3` | Optional cat-ear hat (CoreS3 fitment). |
| `…/pedestal-*` | Our optional electronics base (PCA9685 + barrel jack). **`pedestal-sg90`** mates the vendored v1.0 `feet_SG90M` (48 × 37, screw-down — see step 7); the older generic `pedestal.scad` is unchanged. |

Print note: this set is toleranced for **resin**. On FDM/PLA, open the servo
pockets / screw holes slightly or scale those features ~102–103%.

## Servos

- **2 × MG90S** (metal-gear, ~13.4 g micro servos), plain **PWM** (no IDs — unlike XL330).
  This is what the build uses. **SG90 / MS18** (plastic-gear, ~9 g) are
  pin/PWM/horn-compatible drop-ins — fine for this light, low-load head, but the
  MG90S metal gears give better durability and a slightly steadier hold.
- **Fit note:** the MG90S body is **~1–2 mm longer** than SG90, so it's a **snug**
  fit in the Takao pockets (which are cut for SG90). On FDM/PLA open the pockets a
  touch (see the print note above); a plastic-gear SG90/MS18 sits a little looser in
  the same pocket. No firmware or horn change either way.
- **Pan (yaw)** servo → drives rotation on the feet. Wire to **PCA9685 ch0**.
- **Tilt (pitch)** servo → drives head up/down. Wire to **PCA9685 ch1**.
- Firmware already matches: `src/hal/Servos.cpp` `writeYaw_`→ch0, `writePitch_`→ch1,
  limits **yaw ±45°, pitch ±25°**. No firmware change needed for this shell.
- Power the servos from a **dedicated 5 V** rail (barrel jack → PCA9685 V+),
  common ground with the CoreS3. Don't run servo power off the CoreS3 rail.

## Assembly sequence

1. **Center the servos first.** Power each servo and command it to its mid
   position (90°) *before* attaching horns, so the mechanism's range is centered.
2. **Pan servo → feet.** Screw the round horn to the **feet** center hub.
   Seat the pan servo body into the **bracket's lower pocket** so its output
   shaft engages that horn — the assembly now rotates on the feet.
3. **Tilt servo → bracket.** Seat the second servo in the **bracket's upper
   pocket** (output shaft on the head-tilt axis).
4. **Head.** Attach the **shell** to the tilt servo's horn; route both servo
   cables down through the bracket and the feet's center slot.
5. **CoreS3.** Seat the CoreS3 in the shell (display forward).
6. **Wiring.** Pan → PCA9685 ch0, tilt → ch1. PCA9685 I²C + power to the CoreS3
   (Port A Grove `Wire`, or M-Bus `Wire1` G43/G44 per `Servos.cpp`). Servo V+
   from the barrel jack.
7. **Electronics base (optional).** `pedestal-sg90.scad` now mates the
   **vendored v1.0 case feet** (`../case_SG90/feet_SG90M`, 48 × 37 mm — print the
   **M variant**, which has the 4 pilot holes; `feet_MG90S2M` for the MG90S
   build). It no longer fits the 54 × 50 Takao feet. Assembly:
   1. Feed the servo cables/connectors down through the pedestal's center hole
      and back slot **before** seating the feet.
   2. Drop the feet into the top recess, **cable slot toward the barrel jack**
      (the offset recess only allows this orientation).
   3. With the bottom plate off, drive **4 × M2×8 pan-head screws from inside
      the cavity** up into the feet's pilot holes.
   4. The pan-horn screw stays reachable from inside through the Ø22 center
      hole. Then mount the PCA9685 plate as usual.
8. **Hat** (optional) on top.

## Movement / care
- Keep within the firmware limits (yaw ±45°, pitch ±25°) — gentle desktop motion.
- Don't back-drive a powered servo by hand.

## Other design (NOT used here)
The M5 **K151** shell (`M5_Hardware/Products/K151_StackChan/`) is built for
**DYNAMIXEL XL330-M288-T** serial-bus servos (IDs 1/2, TTL bus, tilt 5–85°). It
is **incompatible** with MG90S/SG90 PWM servos and the PCA9685. We chose the SG90
Takao shell (driven by MG90S) instead so the existing PCA9685 firmware applies unchanged.

## Sources
- SG90 STLs: https://github.com/mongonta0716/3DPrinter_Models
- Takao stack-chan project: https://github.com/meganetaaan/stack-chan
- (K151/XL330 reference) https://docs.m5stack.com/en/arduino/stackchan/servo

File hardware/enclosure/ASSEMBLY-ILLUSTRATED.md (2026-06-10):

# Stack-chan (MG90S / SG90 · Takao) — Illustrated Assembly

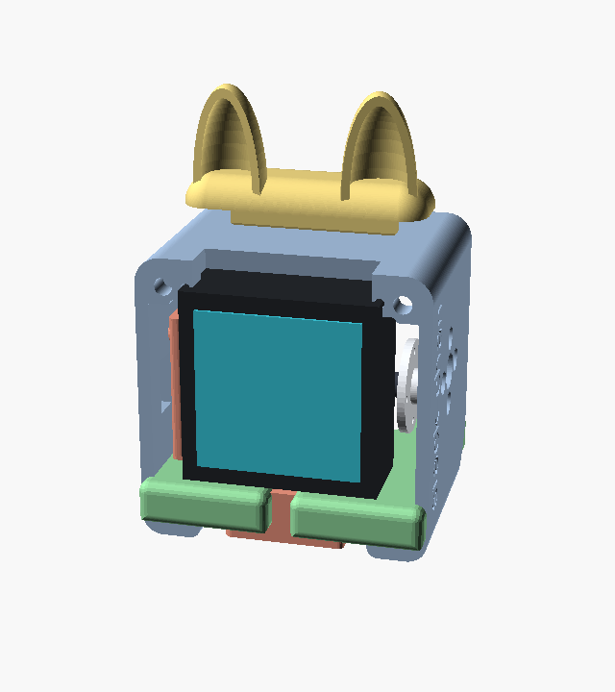
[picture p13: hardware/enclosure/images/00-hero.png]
Assembled Stack-chan: CoreS3 face, cat-ear hat, on the SG90 Takao base


A picture-by-picture build of the **"stack-chan_takao_base"** shell (the upstream
"SG90 case" set), driven by **MG90S** servos on our CoreS3 + **PCA9685** firmware.
This is the visual companion to [`ASSEMBLY.md`](ASSEMBLY.md) — read that for the
fitment notes, print tolerances, and the reasoning behind choosing this shell over
the K151/XL330 design. The images here are rendered from the **actual Takao STLs**;
the servos and the CoreS3 are simple stand-ins (we don't have STLs for them) so you
can see where each one goes.

> **Orientation used in every render:** the **display faces −Y (front)**, the
> head **pans (yaw)** about the vertical **Z** axis at the base, and **tilts
> (pitch)** about the left–right **X** axis through the head. This matches the
> firmware: yaw → **PCA9685 ch0** (±45°), pitch → **ch1** (±25°).

---

## Bill of materials

| # | Part | Qty | Notes |
|---|---|-----|---|
| 1 | `stackchan_takao_shell_v2_resin` | 1 | Head shell — wraps the CoreS3; speaker grille + "stack-chan" emboss on one side |
| 2 | `stackchan_takao_bracket_v2.5` | 1 | Servo bracket — holds **both** servos (pan lower, tilt upper) |
| 3 | `stackchan_takao_feet` | 1 | Base — two pads + a centre hub with the round-horn bolt pattern |
| 4 | `stackchan_takao_hat_cat_CoreS3` | 1 | Optional cat-ear hat |
| 5 | **MG90S** metal-gear micro servo (PWM) | 2 | One pan (yaw), one tilt (pitch) — plus round horns + screws. **SG90 / MS18** (plastic-gear, ~9 g) are drop-in compatible. |
| 6 | **M5Stack CoreS3** | 1 | Display faces front |
| 7 | PCA9685 + 5 V supply (barrel jack) | 1 | Servo driver; see the optional [`pedestal.scad`](pedestal-sg90.scad) base |

Printed parts are toleranced for **resin**; on FDM/PLA open the servo pockets and
screw holes slightly (≈102–103 %). See [`ASSEMBLY.md`](ASSEMBLY.md#printed-parts-sg90-takao-set).

> **Servo fit:** the **MG90S** body is ~1–2 mm longer than SG90, so it's a **snug**
> fit in the Takao pockets (which are cut for SG90); a plastic-gear **SG90/MS18**
> sits a little looser in the same pocket. Either works with no firmware or horn
> change — MG90S just trades a few grams for metal-gear durability.

---

## Printed parts

| Feet | Bracket |
|:---:|:---:|
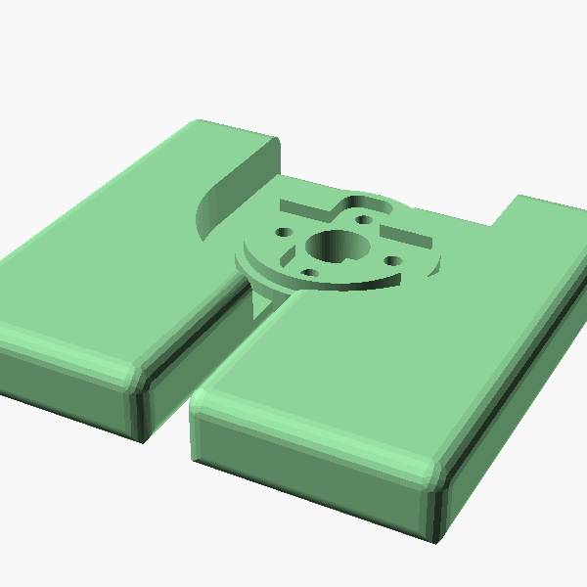
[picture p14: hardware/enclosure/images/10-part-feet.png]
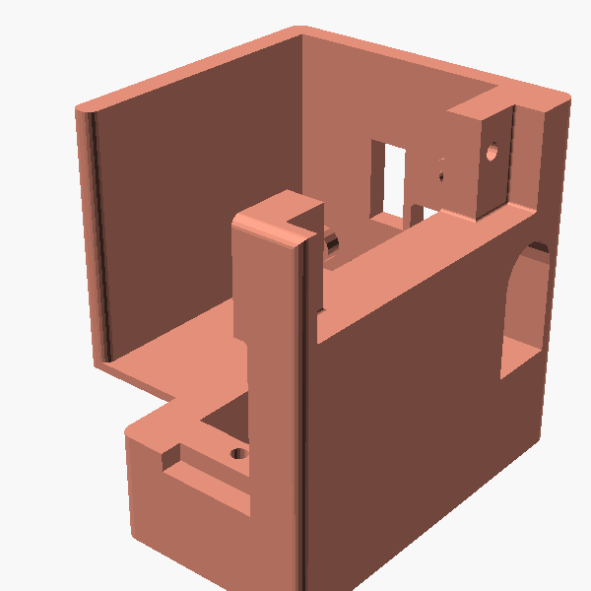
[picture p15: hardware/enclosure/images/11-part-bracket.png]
|  |  |
| Two pads + centre hub. The disc of holes is the **round-horn bolt pattern** (MG90S/SG90) — the pan horn screws here. The slot routes the servo cables down. | Chair-shaped. The **rectangular pocket** in the back wall takes the **tilt** servo body; the lower cradle holds the **pan** servo. |

| Head shell | Cat-ear hat |
|:---:|:---:|
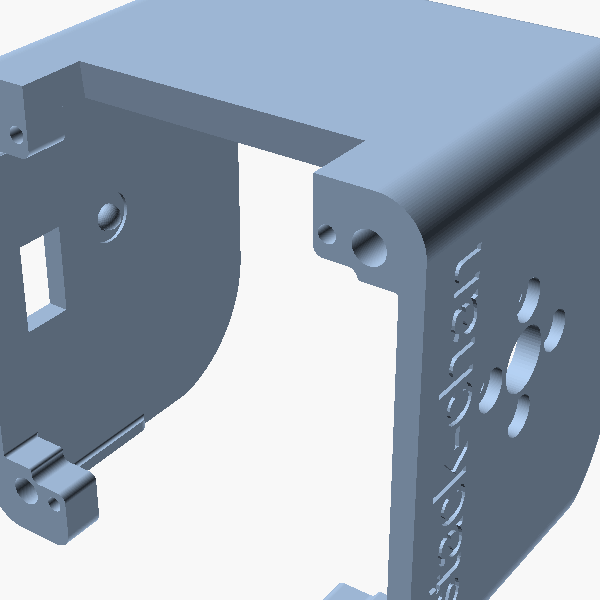
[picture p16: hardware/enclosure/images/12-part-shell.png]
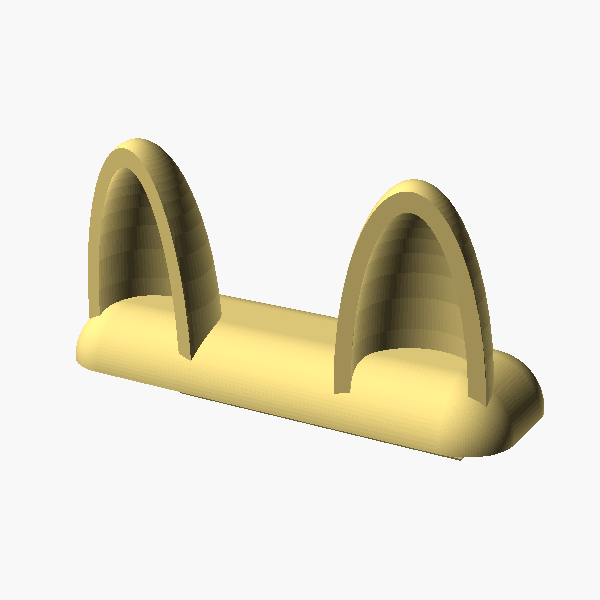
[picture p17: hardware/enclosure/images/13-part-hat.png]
|  |  |
| Open front (display) and back; solid sides. One side carries the speaker grille + "stack-chan" logo. The inner side walls hold the **tilt pivot**. | Optional. Clips onto the top of the head. |

### Stand-ins (not printed — shown for clarity)

| MG90S servo (×2) | M5Stack CoreS3 |
|:---:|:---:|
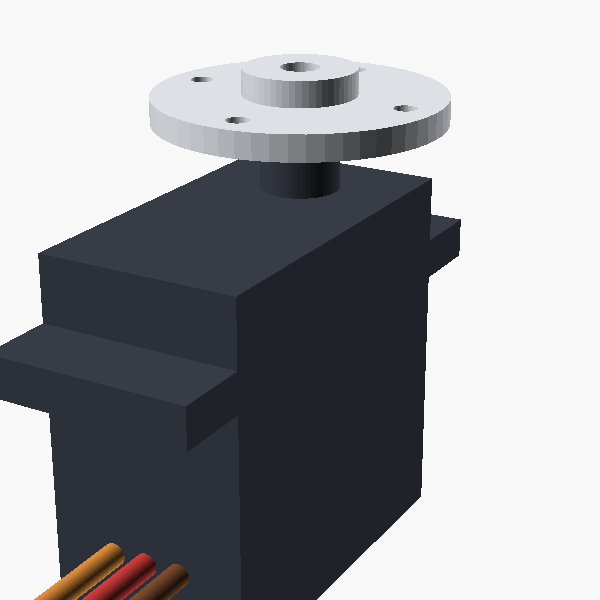
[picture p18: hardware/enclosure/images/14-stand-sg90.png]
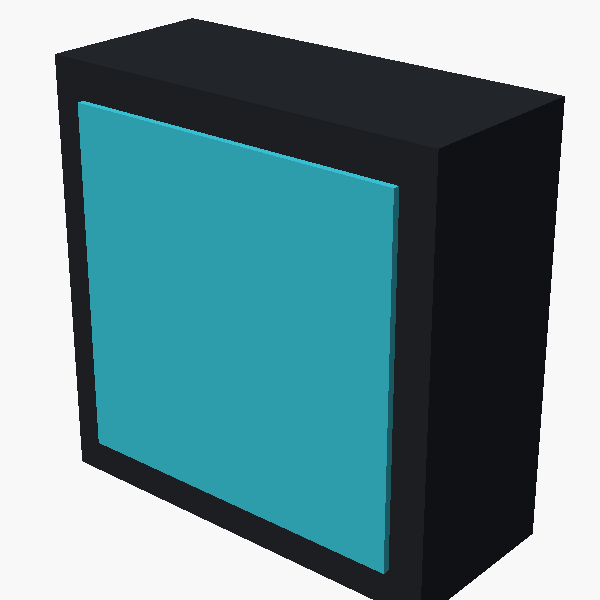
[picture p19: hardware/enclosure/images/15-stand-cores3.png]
|  |  |
| Body + mounting flange, output shaft, **round horn**, and the 3-wire lead (signal/+5 V/GND). Same body class as SG90/MS18. | Display module that seats in the head, screen forward. |

---

## Exploded view

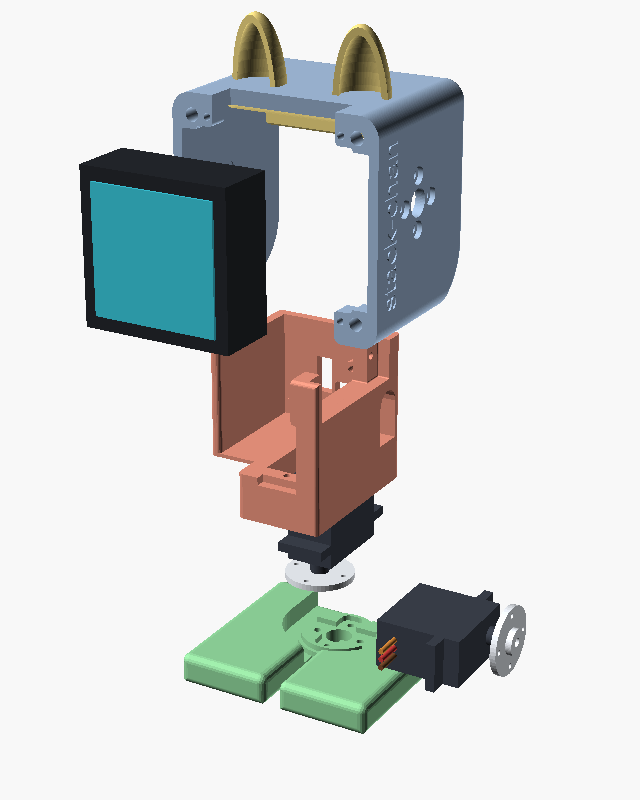
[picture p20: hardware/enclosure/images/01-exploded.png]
Exploded view of all parts


Top → bottom along the build axis: **hat → head shell → CoreS3** (pulled to the
front) **→ bracket → tilt servo** (pulled to the side) **→ pan servo → feet**.

---

## Assembly sequence

### 1 · Centre both servos first
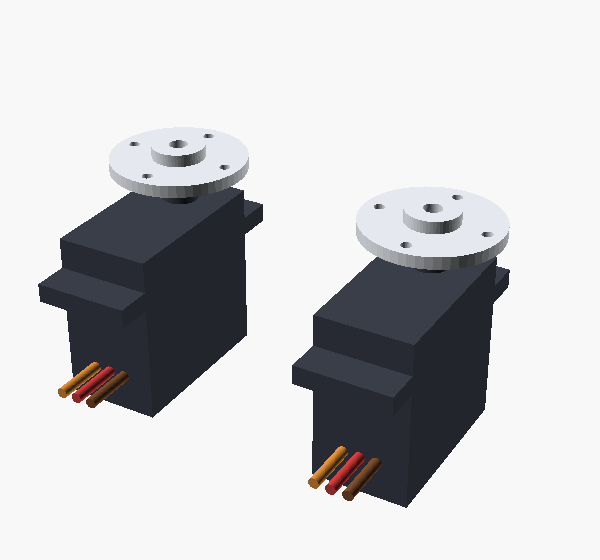
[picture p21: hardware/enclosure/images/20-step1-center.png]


Power each servo and command it to its **mid position (90°)** *before* attaching
any horn, so the mechanism's travel ends up centred. Do this for both the pan and
the tilt servo.

<br clear="all">

### 2 · Pan servo → feet
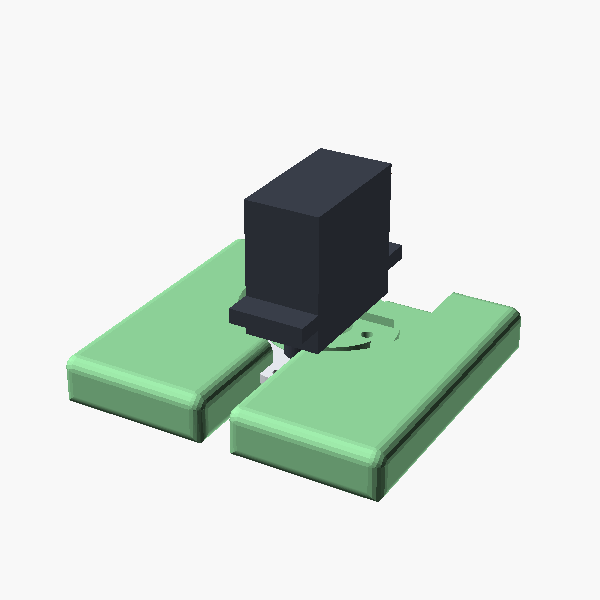
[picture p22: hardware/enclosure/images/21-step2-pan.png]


Screw the **round horn** to the **feet centre hub**. Seat the pan servo body so
its output shaft engages that horn, pointing **down** into the hub. Because the
horn is fixed to the (stationary) feet, the servo body — and everything above it —
will **rotate on the feet**. This is the **yaw** axis → **PCA9685 ch0**.

<br clear="all">

### 3 · Tilt servo → bracket
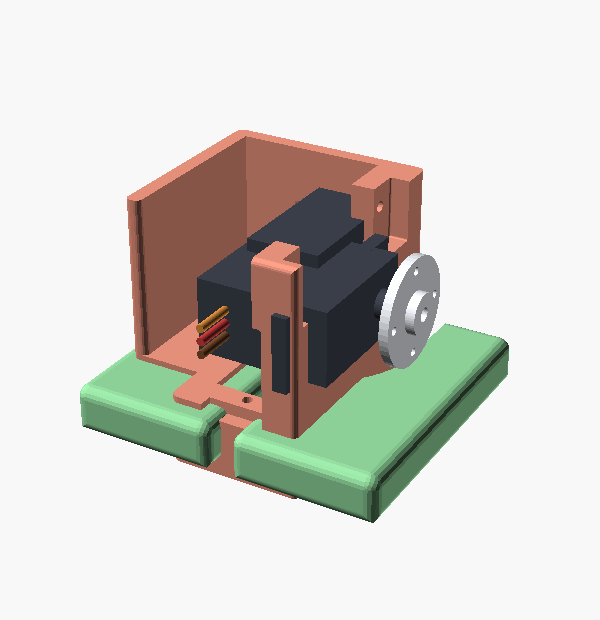
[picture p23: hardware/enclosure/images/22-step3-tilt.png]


Drop the **bracket** over the pan servo (its lower cradle captures the pan servo
body). Seat the second servo in the bracket's **upper pocket** with its shaft
**horizontal**, on the head-tilt axis. This is the **pitch** axis → **ch1**.
Route both servo leads down through the bracket and the feet's centre slot.

<br clear="all">

### 4 · Head shell on
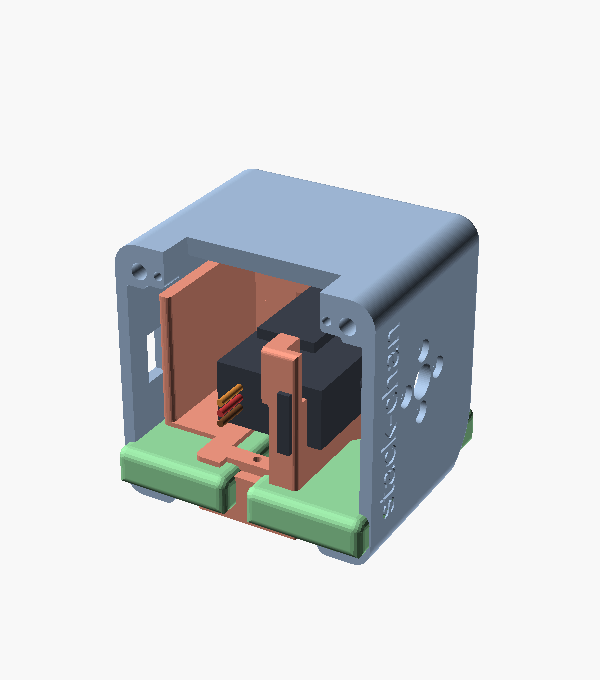
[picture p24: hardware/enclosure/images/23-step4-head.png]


Lower the **shell** onto the tilt servo: the head's side-wall pivots line up with
the tilt servo shaft (one side) and a free pivot screw (the other). The head now
**nods** on the bracket. Keep the open face pointing **front (−Y)**.

<br clear="all">

### 5 · Seat the CoreS3
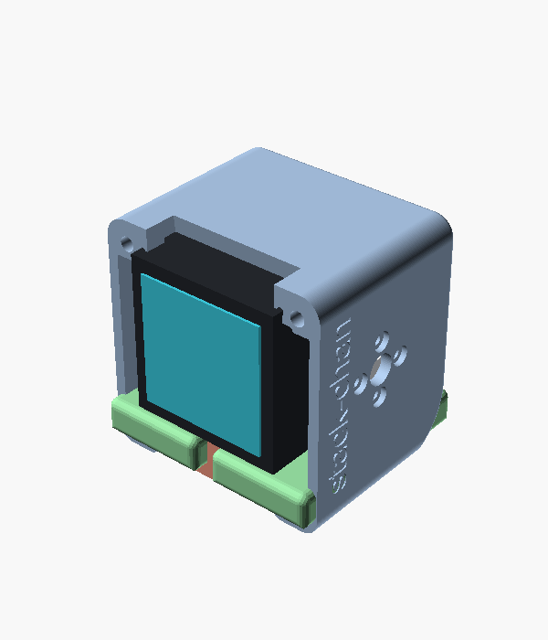
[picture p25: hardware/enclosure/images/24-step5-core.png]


Slide the **CoreS3** into the head with the **display facing forward**. Its USB-C
and buttons stay accessible at the edges; the servo leads exit below toward the
PCA9685.

<br clear="all">

### 6 · Hat (optional)
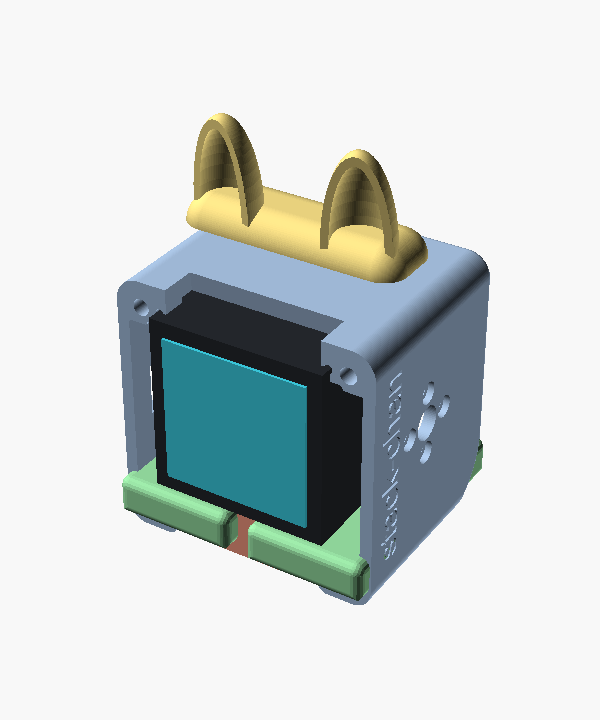
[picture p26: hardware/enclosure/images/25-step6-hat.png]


Clip the **cat-ear hat** onto the top of the head. Done — stack-chan is assembled.

<br clear="all">

---

## Wiring & power

- **Pan** servo → **PCA9685 ch0**   ·   **Tilt** servo → **PCA9685 ch1**
  (matches `src/hal/Servos.cpp`: `writeYaw_`→ch0, `writePitch_`→ch1).
- Power the servos from a **dedicated 5 V** rail (barrel jack → PCA9685 **V+**),
  sharing a **common ground** with the CoreS3. **Do not** run servo power off the
  CoreS3 rail.
- PCA9685 I²C + power to the CoreS3 (Port A Grove `Wire`, or M-Bus `Wire1`
  G43/G44 per `Servos.cpp`).
- Optional electronics base: drop the feet into the pedestal's top recess; the
  PCA9685 + barrel jack live inside. See [`pedestal-sg90.scad`](pedestal-sg90.scad).

## Movement & care

- Stay within the firmware limits (**yaw ±45°, pitch ±25°**) — gentle desk motion.
- Never **back-drive a powered servo** by hand.

---

## Regenerating these images

The renders come from one OpenSCAD scene, driven headless (no display needed):

```sh
# needs: openscad, and the upstream Takao STL set (see Sources)
STL_DIR=~/cloned/stackchan-sg90-models/stackchan_sg90_case_takao_version \
  hardware/enclosure/tools/render-assembly.sh
```

- Scene: [`scene/assembly.scad`](scene/assembly.scad) — STL imports + servo/CoreS3
  stand-ins, posed per stage (`-D 'stage="exploded"'`, `step1`…`step6`, etc.).
- Renderer: [`tools/render-assembly.sh`](tools/render-assembly.sh) — writes every
  PNG in [`images/`](images/) (~2 s for the whole set).

## Sources & attribution

- SG90 Takao STLs (head shell, bracket, feet, hat): **Takao Akaki**, via
  [`mongonta0716/3DPrinter_Models`](https://github.com/mongonta0716/3DPrinter_Models)
  (`stackchan_sg90_case_takao_version`). Not redistributed in this repo — clone
  upstream and point `STL_DIR` at it.
- Stack-chan project: <https://github.com/meganetaaan/stack-chan>

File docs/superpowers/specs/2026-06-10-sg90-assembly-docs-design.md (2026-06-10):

# SG90 Stack-chan — Illustrated Assembly Docs & Images

**Date:** 2026-06-10
**Status:** Built

## Goal

Produce an illustrated, picture-by-picture assembly guide for the **SG90 / Takao**
Stack-chan build, rendered from the actual 3D models, to complement the existing
text-only [`hardware/enclosure/ASSEMBLY.md`](../../../hardware/enclosure/ASSEMBLY.md).

## Decisions (from brainstorming)

- **Depth:** full illustrated guide — a hero shot, an exploded view, a per-part
  catalogue, and one render for each of the 6 assembly steps (~14 images).
- **Stand-ins:** the SG90 servos and the CoreS3 are not STL parts, so model
  simple proxies for them and include them in the renders so fitment is visible.
- **Output:** a *new* doc (`ASSEMBLY-ILLUSTRATED.md`); leave the hand-written
  `ASSEMBLY.md` intact and cross-link the two.

## Approach

Rendering uses **OpenSCAD headless** (the only renderer available on the box;
confirmed it exports PNG with no display, ~0.16 s per STL). One parameterized
scene file imports the real Takao STLs and adds the proxies; a `stage` variable
selects what's drawn; a shell script drives OpenSCAD once per view.

Why this over alternatives: the STLs are the source of truth, OpenSCAD is already
present, renders are near-instant, and committing the generator means the whole
image set regenerates with one command after any tweak.

### Coordinate findings (measured by probing each STL)

The four STLs are each exported in their **own frame** — they do not share a
common origin:

- `shell` & `feet` share X-centre 0 and Y-centre 32; **shell Z origin ≈ tilt axis**.
- `bracket` and `hat` are offset in Y (centres ~16) and must be shifted +15.5 Y
  to nest into the head.
- The head must be **raised onto a short neck** (`SHELL_DZ`) so its front aperture
  clears the feet; otherwise the base crosses the display in the head-on view.

These offsets live as named constants at the top of the scene so they are easy to
re-tune.

## Components

| File | Purpose |
|---|---|
| `hardware/enclosure/scene/assembly.scad` | STL imports + SG90/CoreS3 proxies; `stage` switch + assembly-stack constants |
| `hardware/enclosure/tools/render-assembly.sh` | Renders all ~14 PNGs headless into `images/`; STL set via `STL_DIR` env |
| `hardware/enclosure/images/*.png` | The rendered guide images |
| `hardware/enclosure/ASSEMBLY-ILLUSTRATED.md` | The illustrated doc embedding the images |
| `hardware/enclosure/ASSEMBLY.md` | Existing text guide — unchanged except a link banner |

## Constraints / notes

- The upstream Takao STLs are **not redistributed** in this repo (third-party,
  Takao Akaki / `mongonta0716`). `STL_DIR` points at a local clone; the committed
  PNGs are the durable artifact.
- The servo/CoreS3 proxies are **representative**, not exact CAD — sized to real
  SG90 / CoreS3 dimensions and placed to read clearly, not for interference checks.

## Out of scope

- Animated / turntable renders, photoreal materials, or wiring-harness diagrams.
- The K151 / DYNAMIXEL XL330 design (incompatible; covered in `ASSEMBLY.md`).

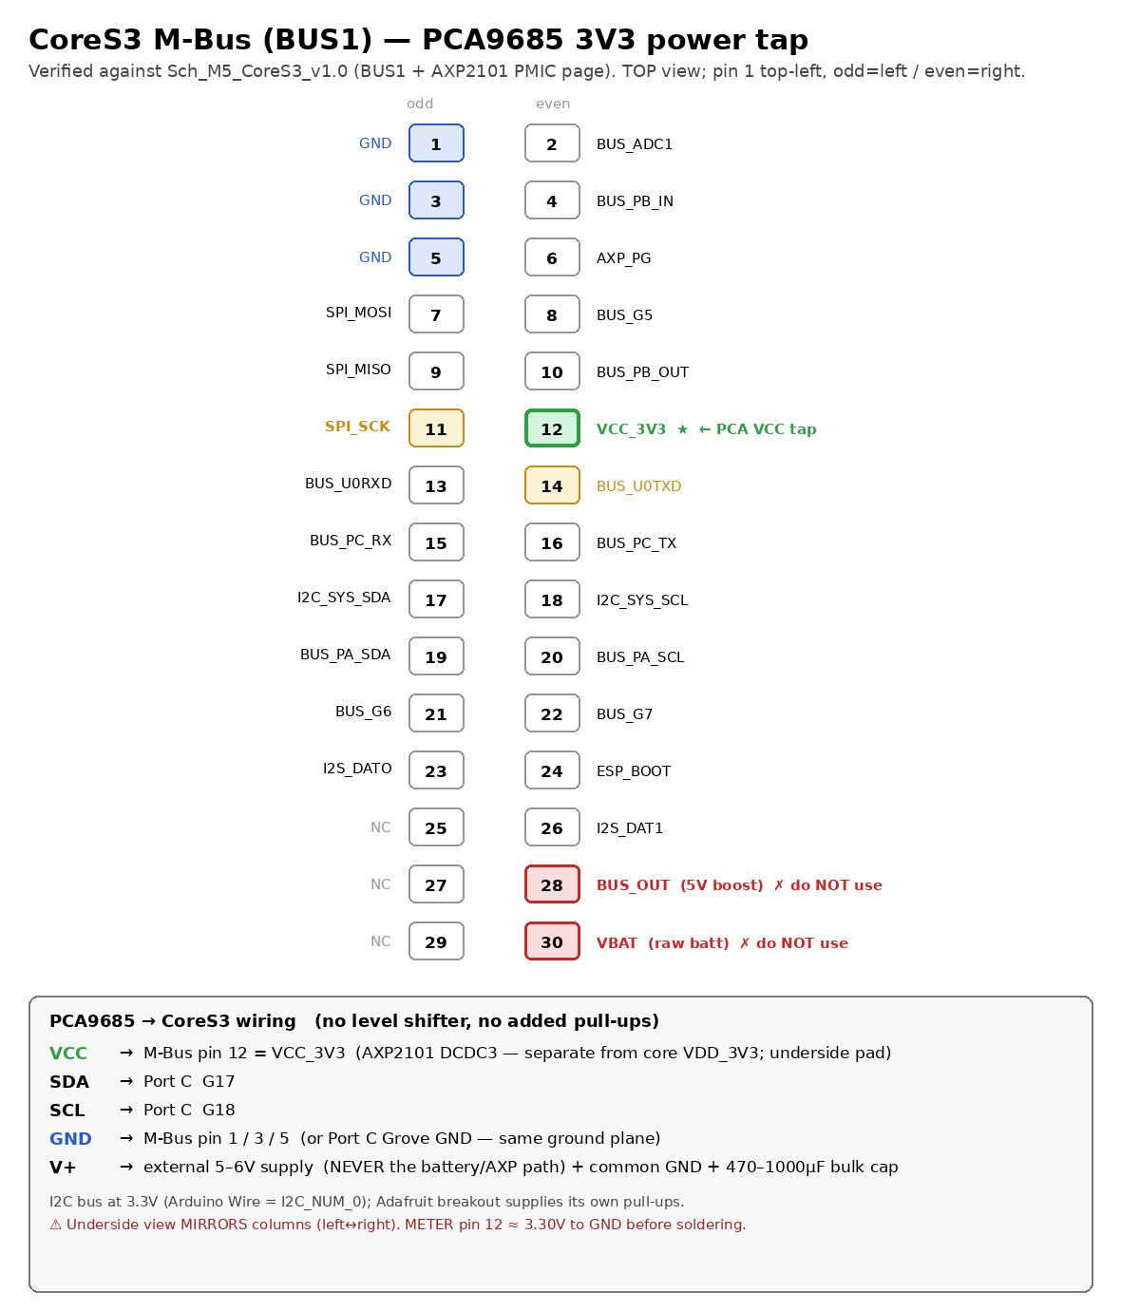
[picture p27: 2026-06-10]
docs/hardware/cores3-pca9685-wiring.png

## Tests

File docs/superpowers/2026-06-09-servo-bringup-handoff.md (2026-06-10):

# Servo / PCA9685 head bring-up — handoff (2026-06-09)

Covers the session that (a) shipped the AXP silent-power-off fix and (b) physically
brought up the 2-servo head (yaw + pitch) on the CoreS3 + DinBase + external PCA9685.
Pairs with the `axp-brownout-state` memory and `src/hal/Servos.cpp` (the wiring lives
in-code there) and the diagram `docs/hardware/cores3-pca9685-wiring.png`.

## TL;DR — where things landed

- **Power-off bug: SOLVED + SHIPPED.** Root cause was an **I2C-controller collision**
  (`Servos::begin()` ran `Wire1.begin(17,18)` = `I2C_NUM_1` = M5Unified's internal AXP
  bus → clobbered a rail → silent off, battery-pull recovery). Fix = drive the PCA on
  Arduino `Wire` (`I2C_NUM_0`), same Port C pins. On `main` (commit `6889e75`), validated
  by 30-min soaks. Full detail in `axp-brownout-state` memory + the banner-marked
  `2026-06-0{6,7}-axp-poweroff-*` docs.
- **Head bring-up: WORKING.** Both axes sweep full range; down-tilt clips the base.
- **Firmware added this session** (commit `829b0d3`, branch `feat/servo-selftest`):
  a boot self-test sweep + clipped `kPitchMin` -25 → -12.

## The validated wiring (this is the source of truth)

Schematic-confirmed (Sch_M5_CoreS3_v1.0: M-Bus `BUS1` + AXP2101 PMIC page), then
physically validated. See the diagram PNG and the `Servos.cpp` header comment.

| PCA9685 | ← from |
|---|---|
| **VCC (logic)** | **M-Bus pin 12 = `VCC_3V3`** (underside DinBase solder pad). AXP2101 **DCDC3**, 3.3V/1.5A, **always-on** — independent of `output_power` (which only gates the 5V boost). |
| **SDA** | Port C **`T`** = G17 |
| **SCL** | Port C **`R`** = G18 |
| **GND** | M-Bus GND (pin 1/3/5) or Port C `G` — same ground plane |
| **V+ (servo motor)** | **separate external 5–6V supply**, common ground, 470–1000µF bulk cap |
| **yaw servo** | PCA **channel 0** |
| **pitch servo** | PCA **channel 1** |

- Powering VCC at 3.3V keeps the bus 3.3V → **no level shifter**; the Adafruit breakout's
  own pull-ups → **no added resistors**. Port C itself has no pull-ups (breakout covers it).
- **Why `Wire`/I2C_NUM_0, never `Wire1`:** `Wire1`==I2C_NUM_1==the internal AXP/codec bus.
  That collision is the power-off bug. Drive the PCA only on `Wire` (I2C_NUM_0).
- **DON'T** tap M-Bus pin 28 (`BUS_OUT` 5V) or pin 30 (`VBAT`) for VCC. Meter pin 12 ≈3.30V
  before soldering.

## Firmware changes this session

- **`src/main.cpp`** — boot self-test sweep in `setup()` (after `servos.begin()`, before the
  loop's idle motion): yaw ±45, pitch +25/-12, eases pumped to completion. Runs only if
  `servos.begin()` succeeded. Wake-up flourish + "are the servos alive / full range" check.
- **`src/hal/Servos.h`** — `kPitchMin` -25 → **-12** (at -25 the chin hit the base/feet).
  -12 still clears the deepest expression ("sad" = -10) and idle nods (±3). `kPitchMax` +25
  unchanged (up has no collision). Yaw stays ±45.
- Note: in normal operation yaw only moves ±8 (idle saccades) and expressions barely touch
  yaw (only "doubt" = -15); the full ±45 sweep is reserved for face-tracking (presence, OFF
  by default) and the boot self-test. So "yaw barely moves at idle" is BY DESIGN.

## Bring-up troubleshooting playbook (hard-won — read before re-debugging servos)

Symptom → cause, in the order they bit us:

1. **PCA detected (no `servo init failed`) but nothing moves** → check, in order:
   **(a) servo V+ rail** (meter the red `V+` row → GND, must read 5–6V; the screw terminal
   often isn't clamping the wire). **(b) OE pin** — active-low; floating/high = all outputs
   off; tie to GND. **(c) servos on ch0/ch1** specifically (ch2–15 are not driven).
   **(d) common ground** between the servo supply and the CoreS3.
2. **Servo only makes "tiny movements" on a big command, free shaft** → NOT mechanical.
   Almost always **current-starved servo supply**. **A computer USB port cannot power
   servos** (~500mA, sags under motor load) — small/slow moves work, big/fast moves stutter.
   Use a dedicated 5–6V / ≥2A source.
3. **One axis works, the other only twitches** → swap the two plugs. Fault **follows the
   servo** = bad servo (or its lead/crimp). Fault **stays on the channel** = bad channel
   signal path. (Ours: the original yaw servo was genuinely dead — twitched even bare.)
4. **Commands drive the wrong axis / "both controls move pitch"** → leftover plug-swap from
   diagnostics. Re-establish: head-turns-L/R servo → ch0, head-tilts-U/D servo → ch1, verify
   with isolated `yaw N / pitch 0` and `yaw 0 / pitch N` commands.
5. **Servo moves but the head axis doesn't** → mechanical. Ours: an **over-tight mounting
   screw seized the yaw rotation** — the servo strained against it. Back the screw off until
   the axis turns freely (snug, not preloaded).

## CoreS3 USB-CDC capture gotchas (cost us a wrong conclusion)

- The CoreS3 is **native USB-Serial/JTAG** (303a:1001). Opening the port with **pyserial
  asserts DTR/RTS by default = the reset line** → your capture **resets the chip on every
  (re)open**. We briefly saw a "12-second reboot loop" that was actually our own
  poll-and-reopen script resetting it. **Fix:** open with `dtr=False; rts=False`.
- The port **hops `/dev/ttyACM0 ↔ ACM1`** on re-enumeration — a known quirk. Tools must glob
  `/dev/ttyACM*`; a fixed-port monitor loses it.
- **Decisive way to remove all USB/host/probe artifacts: run battery-only, observe the
  hardware physically.** This rig has a long history of host/port artifacts masquerading as
  device faults ("the flakiness was the port, not the device").

## Open items / notes

- **Servo supply is still computer USB** — works for one servo at a time, but when both move
  hard together (idle + expression + speech bob during a voice turn) the ~500mA rail may sag.
  A dedicated 5V/2A source is the real fix; not urgent.
- Web `/api/control/servo` does NOT pause idle motion, and a streamed slider restarts the
  400ms ease each value → the head crawls. If web control feels unresponsive, pause idle on
  servo commands (one-liner in `ControlBridge` dispatch) — not done.
- `feat/servo-selftest` (sweep + pitch clip) lands via PR to `main` this session.
- Hardware note for a REAL future PCA on Port C: no external pull-ups there (breakout covers
  it); a bare chip needs ~4.7k, or move to Port A G1/G2 (`M5.Ex_I2C`).
- Carryover: `diag/axp-bisect-builds` retained; SD-logger `stash@{0}` parked.

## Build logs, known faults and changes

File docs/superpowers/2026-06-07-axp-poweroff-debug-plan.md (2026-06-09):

> **⛔ SUPERSEDED (2026-06-09) — root cause FOUND & FIXED.** The silent AXP power-off is an
> **I2C-controller collision**: `Servos::begin()` does `Wire1.begin(17,18)` = `I2C_NUM_1`,
> the SAME controller M5Unified uses for the internal AXP2101 bus → a stray write disables a
> core rail → silent off; the AXP holds the bad state → battery-pull recovery. Source-confirmed
> (`M5Unified.cpp:1620-1631`) + empirically proven. **The current-spike / battery-PCM-OCP /
> "reduce firmware peak current" gates in this plan are VOID** — the answer wasn't a load
> problem. Fix shipped in `src/hal/Servos.cpp` (`Wire1`/I2C_NUM_1 → `Wire`/I2C_NUM_0).
> Canonical record: the `axp-brownout-state` memory. Kept below for historical context only.

# AXP power-off — structured debug plan (2026-06-07)

Branch: `diag/axp-silent-poweroff`. Supersedes the ad-hoc grind; built to escape the
slow/confounded loop. Read with the `axp-brownout-state` memory.

## Honest status (what's actually true)

Split all prior "evidence" into two piles:

- **Trustworthy** — *survivals with continuous heartbeats*: bare-WiFi 54–60 min, and the
  `output_power`, always-on-network-stack, and `M5.update()` eliminations. (A laptop sleep
  would have dropped the port mid-stream, not produced continuous counting, so these hold.)
- **Discard as data** — *every death TIMING*: "deaths within seconds", "stochastic
  30 min–2 h", "6–16 min", "7.6 min", "15 s". All contaminated by laptop auto-suspend
  cutting USB (found 2026-06-07; now permanently disabled + we wrap soaks in
  `systemd-inhibit`).

**One solid new fact:** full app → **silent ~30 min soft-off, clean, n = 1** (vbat+vbus
healthy, zero AXP fault/IRQ change). This is the first trustworthy ground we've had.

**Two failure signatures, not yet reconciled:**
- PRODUCTION (real use, "mixed/random" context per owner): vbat *collapses* 4.15→0.
- LAB (this session, clean): vbat *healthy*, silent off. `powerOff()` on AXP2101 is
  `bitOn(0x10,0x01)` — a soft-off that cuts all rails with NO IRQ — an exact match for the
  lab signature. Whether these are the same bug is an open gate (Gate 4).

Ruled out as cause (measured): hardware (bare ran long), AXP internal OCP/thermal, I2C,
battery-path open, `output_power`, always-on network stack, `M5.update()`/button path,
`bf4b46b` 0x16 ilim write. Nothing in `src/` calls powerOff/timerSleep/deepSleep.

## Method rules (apply to EVERY run from now on)

1. **Sleep inhibited always** — gsettings auto-suspend = `'nothing'` (done) AND wrap each
   capture in `systemd-inhibit --what=idle:sleep --mode=block`.
2. **Recover via POWER BUTTON ONLY** after a death — battery stays on, USB stays in. Do
   NOT toggle the battery switch (it wipes the AXP always-on domain and the latched cause).
3. **Batch unattended** — set a run, walk away, get notified on the port drop. No babysitting.
4. **n ≥ 2 before believing a timing.**

## Gates (decision-tree, ordered by yield — not a fixed ladder)

### Gate 1 — Second-CoreS3 A/B swap  ← LEAD (owner has a 2nd unit)
Flash the SAME current build to unit #2, run sleep-inhibited + unattended.
- Unit #2 **also dies ~30 min** → **FIRMWARE** confirmed (same code, different hardware).
  Proceed to Gate 2/3 on whichever unit.
- Unit #2 **runs > ~1 h clean** → **unit #1 HARDWARE** is the problem (it took days of
  abuse). The bug is unit-specific; production failures were likely this unit degrading.
  Validate by moving the suspect base/cell to #2.
This sidesteps days of firmware soaking. Decisive.

### Gate 0 — Read the bare-vs-full code delta  (free, runs in PARALLEL with every soak)
Structurally diff what the full app inits/runs that the bare loop does not. Hunt for:
timers (grep `1800000`, `180000`, minute math), RTOS tasks (xTaskCreate), any
`M5.Power.*` / library power call, NTP re-sync, web/OTA/keepalive timers. Costs nothing.

### Gate 2 — Repeatable vs stochastic  (cheap, ~2 unattended runs)
Re-run the same build 2–3×. Bisects the whole hypothesis space:
- **Tight cluster near ~30 min** → a deterministic **timer/counter** fires (then chase the
  exact code path from Gate 0's grep — 30 min is suspiciously round).
- **Wide spread** → **load/event-driven** → subtractive subsystem bisection.

### Gate 3 — Read the AXP latch at boot  (one death, high yield)
Add to firmware: read the FULL AXP register bank as the FIRST I2C op at boot, BEFORE
`M5.begin()`, and print it. Combined with power-button-only recovery, a soft-off leaves
the PMIC always-on domain powered → the next boot prints what latched. Also add reg `0x10`
to the live `[AXPT]` trail as backup. One captured death may hand us the cause.

### Gate 4 — Reconcile production (collapse) vs lab (silent)
Decide explicitly if they're the same failure. If Gate 1 says firmware and the lab death
is silent while production collapsed, confirm we're chasing the bug the owner actually hit
(not a lab ghost). Cross-check: does unit running normally (battery only, no laptop) power
off at ~30 min too?

### Then (only if gates don't resolve) — Subtractive bisection
From the full app, `#if`-out one subsystem at a time (display/LVGL → audio → motion),
sleep-inhibited, on Gate 2's branch. Death is fast-ish; a survival clears that subsystem.

### Escalation — hardware scope
If firmware instrumentation can't see the cause: logic-analyzer / scope on the PWRON line
+ the 3V3/5V rails to catch a sub-ms event or a PWRON assertion directly.

## Tools
- `tools/fast-flash.sh` — catch the port + direct esptool (beats the brown-out window).
- `tools/fast-capture.sh` — poll ttyACM*, cat until real drop (timeout-vs-drop aware).
- Capture log: `/tmp/stkchan_boot.log`. AXP IRQ decode: `axp2101_irq_t` in
  `.pio/libdeps/cores3/M5Unified/src/utility/power/AXP2101_Class.hpp`.

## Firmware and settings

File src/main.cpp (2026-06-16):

// Stack-chan v1 — entry point.
// See docs/superpowers/specs/2026-06-02-stackchan-design.md
#include <Arduino.h>
#include <M5CoreS3.h>
#include <WiFi.h>

#include <ArduinoJson.h>

#include "config.h"
#include "services/NvsStore.h"
#include "services/OtaService.h"
#include "services/CaptivePortal.h"
#include "net/WifiManager.h"
#include "net/ConnectivityTier.h"
#include "net/SttClient.h"     // not strictly needed in main but pulls externs
#include "net/ChatClient.h"
#include "net/TtsClient.h"
#include "hal/AudioPlayer.h"
#include "hal/MicRecorder.h"
#include "hal/Servos.h"
#include "hal/Display.h"
#include "face/Face.h"
#include "face/LvglDisplay.h"
#include "face/MenuScreen.h"
#include "motion/MotionDirector.h"
#include "state_machine.h"
#include "app/ControlBridge.h"
#include "vision/PresenceSensor.h"
#include "prompts/greetings.h"


using namespace stkchan;

static bool    g_pressedLast = false;
static int16_t g_pressStartY = 0;
static bool    g_swipeFired  = false;   // latches per-press so we only fire once

// ── USB-serial WiFi provisioning ───────────────────────────────────────────
// No captive-portal hotspot. On first boot with no saved WiFi creds, the
// device waits for a single line of JSON on USB serial:
//   {"ssid":"MyNet","psk":"secret"}            (slot 1)
//   {"ssid1":"A","psk1":"a","ssid2":"B","psk2":"b"}   (multi-slot also OK)
// Sent by tools/provision-serial.py (or just typed into a serial monitor).
// On a valid line we persist to NVS and reboot into normal operation.
static bool tryConsumeProvisioningLine(const String& line) {
  JsonDocument doc;
  if (deserializeJson(doc, line)) return false;

  // Accept either {"ssid","psk"} or explicit slot keys.
  String s1 = doc["ssid1"] | doc["ssid"] | "";
  String p1 = doc["psk1"]  | doc["psk"]  | doc["password"] | "";
  if (s1.isEmpty()) return false;

  nvs.putString(kNvsSsid1, s1);
  nvs.putString(kNvsPsk1,  p1);
  String s2 = doc["ssid2"] | "";
  if (!s2.isEmpty()) { nvs.putString(kNvsSsid2, s2); nvs.putString(kNvsPsk2, doc["psk2"] | ""); }
  String s3 = doc["ssid3"] | "";
  if (!s3.isEmpty()) { nvs.putString(kNvsSsid3, s3); nvs.putString(kNvsPsk3, doc["psk3"] | ""); }

  // Optional: accept other config keys in the same blob so a one-shot
  // provision can set the OpenAI key etc. without the web UI.
  const char* passKeys[][2] = {
    {"chat_host", kNvsChatHost}, {"oai_key", kNvsOaiKey}, {"ota_pass", kNvsOtaPass},
    {"tts_voice", kNvsTtsVoice}, {"tts_provider", kNvsTtsProv},
  };
  for (auto& kv : passKeys) {
    const char* v = doc[kv[0]] | (const char*)nullptr;
    if (v && *v) nvs.putString(kv[1], String(v));
  }

  Serial.printf("[PROV] saved ssid=\"%s\" — rebooting\n", s1.c_str());
  return true;
}

// Non-blocking serial line accumulator. Call frequently. On a complete
// line that parses as a provisioning blob, persists + reboots. Safe to
// call anytime — non-JSON / non-provisioning lines are ignored. This is
// the always-available escape hatch: you can (re)send WiFi creds over USB
// even after a wrong password was saved, since WiFi-not-connected means
// the web UI is unreachable.
static void pollSerialProvisioning() {
  static String line;
  while (Serial.available()) {
    char c = (char)Serial.read();
    if (c == '\n' || c == '\r') {
      line.trim();
      if (line.length() && tryConsumeProvisioningLine(line)) {
        delay(200);
        ESP.restart();
      }
      line = "";
    } else if (line.length() < 1024) {
      line += c;
    }
  }
}

// Block at boot until provisioned over serial. Keeps the LVGL face alive
// and shows a setup prompt on screen.
static void runSerialProvisioning() {
  Serial.println("[PROV] No WiFi creds. Send JSON over serial, e.g.:");
  Serial.println("[PROV]   {\"ssid\":\"YourNet\",\"psk\":\"password\"}");
  Serial.println("[PROV]   (use tools/provision-serial.py, or type + Enter)");
  display.showStatusOverlay("setup: send WiFi over USB", 0xFFE0);

  for (;;) {
    lvglDisplay.tick();
    pollSerialProvisioning();  // reboots on success
    delay(10);
  }
}


void setup() {

  // CoreS3 power: DISABLE the 5V bus-boost (output_power). Evidence: identical
  // firmware died in ~3 min on a strong charger but ran ~2 h on a weak computer
  // USB port. A stronger supply dying FASTER rules out brownout/marginal-supply
  // and points at the boost: on a weak supply the battery buffers the rail; on a
  // strong supply the battery floats and the SY7088 5V boost (BUS_EN) has no
  // battery to lean on — the documented "bus boost wants a battery → ~3 min"
  // failure (see reference-cores3-hardware). We drive NOTHING from the Grove /
  // M-Bus 5V (PCA9685 runs on 3V3, servos on an external supply), so turning the
  // boost off removes an unstable consumer at zero functional cost. Reversible.
  auto cfg = M5.config();
  cfg.output_power = false;
  M5.begin(cfg);
  Serial.begin(115200);
  delay(200);
  Serial.println("\n=== Stack-chan v1 boot ===");
  // Why did we last reset? Prints on the NEXT boot (survives the USB-CDC drop),
  // so a crash that reboots reveals its cause. 1=POWERON 2=EXT 3=SW 4=PANIC
  // 5=INT_WDT 6=TASK_WDT 7=WDT 8=DEEPSLEEP 9=BROWNOUT.
  Serial.printf("[BOOT] reset reason: %d\n", (int)esp_reset_reason());

  if (!nvs.begin()) {
    Serial.println("WARN: NVS open failed");
  }

  display.begin();
  face.begin();
  menu.begin();
  if (!audio.begin()) {
    Serial.println("WARN: AudioPlayer init failed");
  }

  bool servosOk = servos.begin();
  if (!servosOk) {
    Serial.println("WARN: servo init failed");
  }
  motion.begin();

  // Servo self-test sweep — runs ONCE at boot, before the loop's idle motion
  // starts, so it exercises the FULL yaw/pitch travel with no interference. Idle
  // only nudges yaw +/-8, so this is the way to verify the real mechanical range
  // (and it doubles as a "wake up" flourish). Each ease is pumped to completion
  // here because loop()/motion.tick() isn't running yet.
  if (servosOk) {
    Serial.println("[SERVO] self-test sweep: yaw +/-45, pitch +/-25");
    auto sweep = [](int yaw, int pitch, uint32_t ms) {
      servos.easeYawTo(yaw, ms);
      servos.easePitchTo(pitch, ms);
      uint32_t t0 = millis();
      while (millis() - t0 <= ms + 60) { servos.tick(millis()); delay(10); }
    };
    sweep(0, 0, 300);
    sweep(Servos::kYawMax, 0, 700);     // full right
    sweep(Servos::kYawMin, 0, 1000);    // full left
    sweep(0, 0, 500);                   // yaw center
    sweep(0, Servos::kPitchMax, 500);   // up
    sweep(0, Servos::kPitchMin, 700);   // down
    sweep(0, 0, 400);                   // recenter
  }

#if STKCHAN_PRESENCE
  // On-device camera face-detection presence (perk up / greet / look-toward-you
  // / sleepy). Default-off feature; see config.h. begin() inits the GC0308 +
  // spawns the core-0 infer task. The I2C/coexistence + power behaviour MUST be
  // validated by the on-device spike before trusting this on battery.
  if (!presence.begin()) {
    Serial.println("WARN: presence sensor init failed");
  }
#endif

  if (!mic.begin()) {
    Serial.println("WARN: mic alloc failed");
  }

  // Provisioning gate (v2): no SSID1 in NVS → wait for USB-serial creds.
  // No hotspot. tools/provision-serial.py (or a serial monitor) sends a
  // JSON line; we persist + reboot.
  if (nvs.getString(kNvsSsid1, "").isEmpty()) {
    runSerialProvisioning();  // never returns — reboots on success
  }

  controlBridge.begin();   // queue for web → main-loop control commands

  wifi.begin();
  connectivity.begin();

  // v2: bring up the always-on LAN control server once WiFi is connected.
  // Reachable at http://stackchan.local/ from any browser on the network.
  if (wifi.isConnected()) {
    portal.beginLan();
  }

  initStateMachine();
}

void loop() {
  static bool ota_begun = false;
  uint32_t now = millis();

  M5.update();


  lvglDisplay.tick();
  face.tick(now);
  wifi.tick();

  // Top-right debug readout: live servo pitch/yaw. Refreshed ~4 Hz so it tracks
  // moves without spamming the LVGL label every loop().
  static uint32_t s_lastServoDbgMs = 0;
  if (now - s_lastServoDbgMs >= 250) {
    s_lastServoDbgMs = now;
    face.setServoDebug(servos.currentYaw(), servos.currentPitch());
  }

  // Discreet face status (battery + WiFi), refreshed ~every 2 s. Battery via
  // the AXP2101 (M5.Power); WiFi from the live link state.
  static uint32_t s_lastStatusMs  = 0;
  static bool     s_lowBattWarned = false;
  static int      s_lowStreak     = 0;
  if (now - s_lastStatusMs >= 2000) {
    s_lastStatusMs = now;
    // Voltage-based: the AXP2101 fuel-gauge % is unreliable on CoreS3, so we
    // use battery voltage (direct ADC) and treat high VBUS as "on USB power".
    int  vbat = M5.Power.getBatteryVoltage();      // mV
    int  vbus = M5.Power.getVBUSVoltage();         // mV
    // NB: M5.Power.getBatteryCurrent() is hardcoded to 0 on CoreS3 (the AXP2101
    // has no battery-current ADC), so we log AXP DIE TEMPERATURE instead — it
    // reads live (reg 0x3C) and directly tests the DIE_OVER_TEMP shutdown path.
    int  dieC = (int)M5.Power.Axp2101.getInternalTemperature();
    bool ext  = (vbus >= kVbusPresentMv) || ((int)M5.Power.isCharging() == 1);
    int  pct  = batteryPctFromMv(vbat);
    face.setStatus(pct, ext, wifi.isConnected());
    // heap/psram included to catch a per-voice-turn memory leak (the crash
    // happens after a couple interactions). If free heap / min-free-heap trends
    // DOWN each turn, that's a leak; getMinFreeHeap is the all-time low-water.
    // maxblk = largest contiguous free block. If it shrinks toward ~40 KB while
    // heap stays high, that's TLS FRAGMENTATION (each HTTPS handshake — STT+TTS,
    // 2/turn — grabs ~40 KB then frees it fragmented) → next handshake fails.
    Serial.printf("[PWR] vbat=%dmV vbus=%dmV die=%dC chg=%d pct=%d ext=%d | heap=%u min=%u maxblk=%u psram=%u\n",
                  vbat, vbus, dieC, (int)M5.Power.isCharging(), pct, (int)ext,
                  (unsigned)ESP.getFreeHeap(), (unsigned)ESP.getMinFreeHeap(),
                  (unsigned)ESP.getMaxAllocHeap(), (unsigned)ESP.getFreePsram());

    // One-shot spoken low-battery cue: gated on external power, debounced
    // (~10 s sustained) + 30 s boot grace to avoid AXP settling false alarms.
    bool lowNow = (!ext && vbat > 0 && vbat <= kLowBattMv);
    s_lowStreak = lowNow ? s_lowStreak + 1 : 0;
    if (ext || vbat <= 0 || vbat >= kLowBattClearMv) {
      s_lowBattWarned = false;                     // re-arm once recovered/on USB
    }
    if (now >= 30000 && !s_lowBattWarned && s_lowStreak >= 5) {
      // requestExternalSpeak only fires from IDLE; retries next tick if busy.
      if (requestExternalSpeak(String(kLowBattMsg), "sad")) s_lowBattWarned = true;
    }
  }

  // Always-available USB escape hatch: while WiFi is down (e.g. a wrong
  // password was saved and the web UI is unreachable), accept a fresh
  // provisioning line over serial. Reboots on a valid blob.
  if (!wifi.isConnected()) {
    pollSerialProvisioning();
  }

  // T7: OTA — initialize once WiFi connects (ota.tick() is a no-op until begin())
  if (!ota_begun && wifi.isConnected()) {
    ota.begin();
    ota_begun = true;
  }
  ota.tick();

  // v2: start the LAN control server the first time WiFi comes up (covers
  // the case where WiFi wasn't connected yet at the end of setup()).
  static bool lan_begun = false;
  if (!lan_begun && wifi.isConnected()) {
    portal.beginLan();   // idempotent (no-op if already running)
    lan_begun = true;
  }

  connectivity.tick(now);
  motion.tick(now);
  controlBridge.tick();   // apply queued web-control commands on this task

#if STKCHAN_PRESENCE
  // Presence is advisory and IDLE-only: it perks up + greets on arrival, tracks
  // the face, and goes sleepy when the desk empties — but never interrupts a
  // turn. Capture pauses whenever we're not IDLE (frees camera/CPU/power).
  {
    // Also pause during OTA: esp-dl inference reads model weights from flash,
    // which stalls against the OTA writer's cache-disabled erase/write bursts
    // and can fail the upload.
    bool presenceIdle =
        (currentState() == State::IDLE) && !menu.isActive() && !ota.isActive();
    presence.setScanEnabled(presenceIdle);
    presence.tick(now);
    if (presenceIdle) {
      if (presence.consumeArrived()) {
        face.setExpression("happy");
        motion.onExpressionChange("happy");
        motion.startTracking();
        // Spoken greeting: skip if greeted recently; silently degrade to the
        // perk-up above when LAN/TTS is unreachable.
        static uint32_t s_lastGreetMs = 0;
        bool due = (s_lastGreetMs == 0) || (now - s_lastGreetMs >= kGreetCooldownMs);
        if (due && connectivity.current() == Tier::LAN_OK) {
          if (requestExternalSpeak(String(pickGreeting()), "happy")) s_lastGreetMs = now;
        }
      }
      if (presence.consumeLeft()) {
        face.setExpression("sleepy");
        motion.onExpressionChange("sleepy");
        motion.stopTracking();
      }
      // Drive tracking only on a FRESH detection (the ~250 ms infer cadence),
      // not every loop iteration — otherwise each call restarts the servo ease
      // and the head only crawls. takeFreshFace() returns true at most once per
      // new capture.
      if (presence.present()) {
        int cx, cy, w, h;
        if (presence.takeFreshFace(cx, cy, w, h)) {
          motion.lookAt(cx, cy, presence.frameW(), presence.frameH());
        }
      }
    }
  }
#endif

  // Touch → FSM events + swipe-up gesture for menu reveal.
  // When the menu screen is active, LVGL widget handlers own the touch
  // and we skip FSM voice + swipe detection entirely.
  bool pressed = (M5.Touch.getCount() > 0);
  if (menu.isActive()) {
    // LVGL handles the slider / back button. Just reset our local state
    // so the next return-to-face has a clean slate.
    g_pressedLast = pressed;
    g_swipeFired  = false;
    tickStateMachine(now);
    delay(5);
    return;
  }

  // While the floating "Menu" button is showing, let LVGL own touch —
  // tapping anywhere is either "open menu" (button) or "dismiss menu
  // button" (anywhere else). Don't start the mic during that window.
  if (face.isMenuButtonVisible()) {
    g_pressedLast = pressed;
    g_swipeFired  = false;
    tickStateMachine(now);
    delay(5);
    return;
  }

  if (pressed) {
    auto t = M5.Touch.getDetail(0);
    if (!g_pressedLast) {
      // Touch-down: remember start position. Fire the FSM press event so
      // press-to-talk still works.
      g_pressStartY = t.y;
      g_swipeFired  = false;
      Serial.printf("[Touch] down @ (%d,%d)\n", (int)t.x, (int)t.y);
      onPressDown();
    } else if (!g_swipeFired) {
      // Mid-press: check for swipe-up from the bottom edge. Loosened
      // thresholds — allow swipes starting from the bottom half of the
      // screen with only 40 px of upward motion.
      int dy = g_pressStartY - t.y;
      if (g_pressStartY >= 120 && dy >= 40) {
        Serial.printf("[Touch] swipe-up detected (startY=%d, dy=%d)\n",
                      g_pressStartY, dy);
        g_swipeFired = true;
        onPressCancel();
        face.revealMenuButton();
      }
    }
  } else if (g_pressedLast) {
    // Touch-up: fire normal release ONLY if this wasn't a swipe.
    if (!g_swipeFired) onPressUp();
  }
  g_pressedLast = pressed;

  tickStateMachine(now);
  delay(5);
}

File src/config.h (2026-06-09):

#pragma once
// Stack-chan v1 — global constants.
// See spec section 6 (errors) and section 10 (NVS schema).

#include <stddef.h>
#include <stdint.h>

// ── Feature: on-device presence awareness ──────────────────────────────────
// 1 = enable camera face-DETECTION presence behaviors (perk up + greet on
// arrival, servo look-toward-you tracking, sleepy when the desk is empty).
// Default 0: the feature ships dark until the camera/I2C spike clears.
// See vision/PresenceSensor + vision/PresenceLogic.
// #ifndef-guarded so a build flag (-DSTKCHAN_PRESENCE=1) can force it on.
#ifndef STKCHAN_PRESENCE
#define STKCHAN_PRESENCE 0
#endif

namespace stkchan {

// === NVS ===
constexpr const char* kNvsNamespace = "stkchan";  // keys must be <= 15 chars

constexpr const char* kNvsSsid1     = "ssid1";
constexpr const char* kNvsPsk1      = "psk1";
constexpr const char* kNvsSsid2     = "ssid2";
constexpr const char* kNvsPsk2      = "psk2";
constexpr const char* kNvsSsid3     = "ssid3";
constexpr const char* kNvsPsk3      = "psk3";
constexpr const char* kNvsChatHost  = "chat_host";   // casual LLM (direct Ollama)
constexpr const char* kNvsChatModel = "chat_model";
constexpr const char* kNvsBrainHost = "brain_host";  // oc-personal agent runner
constexpr const char* kNvsBrainKey  = "brain_key";   // bearer for the agent (optional)
constexpr const char* kNvsBrainKw   = "brain_kw";    // optional CSV stem override
constexpr const char* kNvsSttUrl    = "stt_url";
constexpr const char* kNvsSttModel  = "stt_model";
constexpr const char* kNvsOaiKey    = "oai_key";
constexpr const char* kNvsTtsProv   = "tts_provider";
constexpr const char* kNvsTtsVoice  = "tts_voice";
constexpr const char* kNvsTtsModel  = "tts_model";
constexpr const char* kNvsElKey     = "el_key";
constexpr const char* kNvsOtaPass   = "ota_pass";
constexpr const char* kNvsPersona   = "persona";
constexpr const char* kNvsSpkVolume = "spk_vol";  // 0-255 M5.Speaker.setVolume
constexpr const char* kNvsPresEnable = "pres_en";   // "1"/"0" presence on/off (NVS override)
constexpr const char* kNvsGreetMin   = "greet_min"; // spoken-greeting cooldown, minutes
constexpr const char* kNvsPresGain    = "pres_gain"; // tracking gain x100 (e.g. "50" = 0.50)

// === Defaults ===
constexpr const char* kDefaultChatModel = "gemma3n:e4b";
constexpr const char* kDefaultSttModel  = "whisper-1";
constexpr const char* kDefaultTtsProv   = "openai";
constexpr const char* kDefaultTtsVoice  = "nova";
constexpr const char* kDefaultTtsModel  = "tts-1";
constexpr int         kDefaultSpkVolume = 230;   // 0-255; 200 was inaudible

// === Battery ===
// The CoreS3 AXP2101 fuel-gauge percentage (getBatteryLevel) is unreliable —
// it can read low even on a full pack. We gate the low-battery cue on battery
// VOLTAGE (a direct ADC read) instead, and derive the displayed % from it.
constexpr int         kLowBattMv      = 3500;  // warn at/below this battery voltage (mV)
constexpr int         kLowBattClearMv = 3700;  // re-arm the cue once recovered above this
constexpr int         kVbusPresentMv  = 4000;  // VBUS above this => on USB/external power
constexpr const char* kLowBattMsg     = "My battery is low. Please plug me in.";

// Rough LiPo voltage(mV) -> percent for a discreet indicator. -1 if unknown.
inline int batteryPctFromMv(int mv) {
    if (mv <= 0)    return -1;
    if (mv >= 4200) return 100;
    if (mv <= 3300) return 0;
    return (int)((long)(mv - 3300) * 100 / (4200 - 3300));
}

// === Brain agent (oc-personal) ===
// The oc-personal runner is an OpenAI-compatible endpoint; model "oc-personal"
// runs the Claude + multi-MCP agent (2ndBrain / Gmail / Calendar).
constexpr const char* kDefaultBrainHost = "http://192.168.1.178:8080";
constexpr const char* kOcPersonalModel  = "oc-personal";
// Utterances containing any of these stems (case-insensitive substring) route
// to the agent instead of the local casual model. NVS "brain_kw" (CSV) overrides.
constexpr const char* kBrainStems[] = {
    "2nd brain", "second brain", "calendar", "schedule", "agenda",
    "my email", "inbox", "my notes",
};
constexpr size_t kBrainStemCount = sizeof(kBrainStems) / sizeof(kBrainStems[0]);

// === NTP / Time ===
// POSIX TZ string (US Central with DST). Override at provisioning time if needed.
constexpr const char* kNtpServer        = "pool.ntp.org";
constexpr const char* kTimezoneDefault  = "CST6CDT,M3.2.0,M11.1.0";

// === WiFi ===
// Per-slot connect budget inside the slot-priority loop (Jarvis PR #20).
constexpr uint32_t kPerSlotTimeoutMs    = 8000;

// === Timeouts (ms) ===
constexpr uint32_t kSttTimeoutMs        = 8000;
constexpr uint32_t kChatTimeoutMs       = 60000;  // cold gemma3n load can be ~20-40s
constexpr uint32_t kTtsTimeoutMs        = 8000;
constexpr uint32_t kTierProbeIntervalMs = 30000;
constexpr uint32_t kMaxRecordMs         = 6000;
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

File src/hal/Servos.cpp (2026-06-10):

#include "hal/Servos.h"
#include <Wire.h>
#include <Adafruit_PWMServoDriver.h>

namespace stkchan {

Servos servos;

// PCA9685 servo driver on CoreS3. I2C SIGNALS on PORT C (G17/G18); LOGIC POWER
// tapped from the M-Bus 3V3 rail. The M-Bus header is occupied by the DinBase
// (which holds the battery), so the original M-Bus servo pins (G43/G44) aren't
// reachable from the top — but every M-Bus pin is exposed as a SOLDER PAD on the
// DinBase underside, so the 3V3 rail is reachable there.
//
// WIRING (schematic-confirmed, Sch_M5_CoreS3_v1.0 / M-Bus "BUS1"; see the diagram
// docs/hardware/cores3-pca9685-wiring.png):
//   PCA SDA  -> G17  (Port C Grove)
//   PCA SCL  -> G18  (Port C Grove)
//   PCA VCC  -> M-Bus pin 12 = VCC_3V3  (underside pad). This is AXP2101 DCDC3,
//              3.3V / 1.5A, and is ALWAYS-ON: it is independent of
//              cfg.output_power (which only gates the separate 5V bus-boost), so
//              the rail is live even though this firmware disables that boost.
//   PCA GND  -> M-Bus GND (pin 1/3/5) OR the Port C Grove GND — same ground plane.
//   Servo V+ -> a SEPARATE external 5-6V supply (NEVER the CoreS3 battery/AXP
//              path), common ground, with a 470-1000uF bulk cap at the PCA V+
//              terminal for inrush/stall.
//   PCA9685 default address 0x40.
//
// Powering VCC at 3.3V keeps the whole I2C bus at 3.3V => NO level shifter, and the
// Adafruit PCA9685 BREAKOUT carries its own SDA/SCL pull-ups (to VCC) => NO added
// pull-up resistors. (A BARE PCA9685 chip would need 2x ~4.7k to 3.3V.)
// ⚠ DON'T tap M-Bus pin 28 (BUS_OUT = 5V boost) or pin 30 (VBAT = raw battery) for
//   VCC — either would overvolt/destroy the 3.3V bus. Verify pin 12 reads ~3.30V to
//   GND with a meter before soldering; watch for bridges to pin 11 (SPI_SCK) / 14
//   (U0TXD). Underside view MIRRORS the columns (left<->right) vs the top.
//
// ⚠ MUST use Arduino `Wire` (I2C_NUM_0), NOT `Wire1` (I2C_NUM_1). On CoreS3,
// M5Unified binds its INTERNAL bus (AXP2101 0x34 + codec/touch/AW9523B) to
// I2C_NUM_1 (M5Unified.cpp:1624) — so `Wire1.begin(17,18)` reconfigured the very
// controller driving the AXP power chip; a stray byte then disabled a rail → the
// long-hunted silent "AXP power-off" (vbat healthy, battery-pull-only recovery).
// Root cause found 2026-06-09; PROVEN by an I2C scan on Wire1/Port C returning the
// whole internal constellation (0x34 AXP, 0x38 touch, 0x40 codec, 0x58 AW9523…).
// I2C_NUM_0 is free (the app uses no Port A / Ex_I2C devices). Port C itself has no
// external pull-ups — fine here because the breakout provides them (above).
constexpr int kServoSDA  = 17;   // Port C
constexpr int kServoSCL  = 18;   // Port C
constexpr uint8_t kServoAddr = 0x40;
static Adafruit_PWMServoDriver g_pwm = Adafruit_PWMServoDriver(kServoAddr, Wire);

// PCA9685 PWM range for SG90: ~150 .. 600 counts at 50 Hz.
static int degToPwm(int deg) {
  // Map -90..+90 onto 150..600. Servo zero ≈ 375.
  long mapped = map(deg, -90, 90, 150, 600);
  return (int)mapped;
}

bool Servos::begin() {
  // Secondary I2C on Port C via Wire (I2C_NUM_0) — see the controller warning above.
  Wire.begin(kServoSDA, kServoSCL, 400000);
  if (!g_pwm.begin()) {
    Serial.println("ERR: PCA9685 init failed (not detected on Wire Port C G17/G18 @0x40)");
    return false;
  }
  g_pwm.setOscillatorFrequency(27000000);
  g_pwm.setPWMFreq(50);
  writeYaw_(0);
  writePitch_(0);
  return true;
}

int Servos::clamp_(int v, int lo, int hi) {
  return v < lo ? lo : (v > hi ? hi : v);
}

void Servos::writeYaw_(int deg) {
  deg = clamp_(deg, kYawMin, kYawMax);
  g_pwm.setPWM(0, 0, degToPwm(deg));
  yawDeg_ = deg;
}
void Servos::writePitch_(int deg) {
  deg = clamp_(deg, kPitchMin, kPitchMax);
  // Tilt servo sits mirrored in the assembled bracket, so the pulse sense is
  // inverted: logical +deg = head UP needs the negated angle on the horn.
  g_pwm.setPWM(1, 0, degToPwm(-deg));
  pitchDeg_ = deg;
}

void Servos::setYaw  (int deg) { eYaw_.active   = false; writeYaw_(deg); }
void Servos::setPitch(int deg) { ePitch_.active = false; writePitch_(deg); }

void Servos::easeYawTo(int deg, uint32_t durMs) {
  eYaw_ = {true, yawDeg_, clamp_(deg, kYawMin, kYawMax), millis(), durMs};
}
void Servos::easePitchTo(int deg, uint32_t durMs) {
  ePitch_ = {true, pitchDeg_, clamp_(deg, kPitchMin, kPitchMax), millis(), durMs};
}

bool Servos::isMoving() const { return eYaw_.active || ePitch_.active; }

static int interp(int from, int to, uint32_t elapsed, uint32_t dur) {
  if (elapsed >= dur) return to;
  float t = (float)elapsed / (float)dur;
  // ease-in-out cubic
  float eased = t < 0.5f ? 4 * t * t * t
                          : 1 - powf(-2 * t + 2, 3) / 2;
  return from + (int)((to - from) * eased);
}

void Servos::tick(uint32_t nowMs) {
  if (eYaw_.active) {
    uint32_t e = nowMs - eYaw_.startMs;
    writeYaw_(interp(eYaw_.from, eYaw_.to, e, eYaw_.durMs));
    if (e >= eYaw_.durMs) eYaw_.active = false;
  }
  if (ePitch_.active) {
    uint32_t e = nowMs - ePitch_.startMs;
    writePitch_(interp(ePitch_.from, ePitch_.to, e, ePitch_.durMs));
    if (e >= ePitch_.durMs) ePitch_.active = false;
  }
}

}  // namespace stkchan

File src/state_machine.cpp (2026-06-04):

#include "state_machine.h"
#include "config.h"
#include "hal/MicRecorder.h"
#include "hal/AudioPlayer.h"
#include "hal/Display.h"
#include "face/Face.h"
#include "motion/MotionDirector.h"
#include "face/ExpressionMap.h"
#include "persona/ResponseParser.h"
#include "persona/SystemPrompt.h"
#include "prompts/persona_examples.h"
#include "net/SttClient.h"
#include "net/ChatClient.h"
#include "net/TtsClient.h"
#include "net/ConnectivityTier.h"
#include "services/NvsStore.h"

#include <freertos/FreeRTOS.h>
#include <freertos/task.h>

namespace stkchan {

static State    g_state         = State::IDLE;
static bool     g_pressFlag     = false;
static bool     g_releaseFlag   = false;
static bool     g_audioDoneFlag = false;
static uint32_t g_pressStartMs  = 0;
static String   g_transcript;
static String   g_replyRaw;
static ParsedReply g_parsed;

// Background chat task: chat.send() can block 5–30 s (esp. the oc-personal
// agent), so we run it off the main loop to keep the LVGL face animating.
static TaskHandle_t  g_chatTask  = nullptr;
static volatile bool g_chatDone  = false;
static volatile bool g_chatOk    = false;
static bool          g_brainMode = false;

// Case-insensitive substring scan of the transcript for any brain stem.
// Routes brain/email/calendar utterances to the oc-personal agent.
static bool transcriptWantsBrain(const String& transcript) {
  String low = transcript;
  low.toLowerCase();
  // Optional NVS CSV override of the default stem list.
  String csv = nvs.getString(kNvsBrainKw, "");
  if (csv.length()) {
    csv.toLowerCase();
    int start = 0;
    while (start < (int)csv.length()) {
      int comma = csv.indexOf(',', start);
      if (comma < 0) comma = csv.length();
      String stem = csv.substring(start, comma); stem.trim();
      if (stem.length() && low.indexOf(stem) >= 0) return true;
      start = comma + 1;
    }
    return false;
  }
  for (size_t i = 0; i < kBrainStemCount; ++i) {
    if (low.indexOf(kBrainStems[i]) >= 0) return true;
  }
  return false;
}

// One-shot worker: runs the (blocking) chat call, then flags completion.
// g_transcript / g_brainMode are set by the FSM before spawn and not touched
// again until g_chatDone is observed, so no extra locking is needed.
static void chatTaskFn(void* /*arg*/) {
  g_chatOk = chat.send(g_transcript, g_replyRaw, g_brainMode);
  g_chatDone = true;   // publish last
  g_chatTask = nullptr;
  vTaskDelete(nullptr);
}

State currentState() { return g_state; }

void onPressDown()  { g_pressFlag   = true; }
void onPressUp()    { g_releaseFlag = true; }
void onAudioDone()  { g_audioDoneFlag = true; }

bool requestExternalSpeak(const String& text, const char* exprTag) {
  if (g_state != State::IDLE) return false;       // busy with a voice turn
  if (text.isEmpty()) return false;
  std::string expr = (exprTag && *exprTag) ? std::string(exprTag) : "neutral";
  g_parsed.speech = std::string(text.c_str());
  g_parsed.expr   = expr;
  g_parsed.ok     = true;
  // Mirror the THINKING_CHAT → SPEAKING_TTS handoff: set face/motion, then
  // let the SPEAKING_TTS tick run the (blocking) synth + playback.
  face.setExpression(expr);
  motion.onExpressionChange(expr);
  motion.startSpeechBob(expressionFor(expr).bobAmp);
  g_state = State::SPEAKING_TTS;
  return true;
}

void onPressCancel() {
  // Abort whatever the FSM is doing right now (mic recording, etc.) and
  // return cleanly to IDLE without speaking an error. Called by main.cpp
  // when a swipe-up gesture is detected mid-press.
  g_pressFlag   = false;
  g_releaseFlag = false;
  if (mic.isActive()) mic.stop();
  if (g_state == State::LISTENING ||
      g_state == State::THINKING_STT ||
      g_state == State::THINKING_CHAT) {
    face.setExpression(std::string("neutral"));
    display.clearOverlay();
    motion.resumeIdle();
    g_state = State::IDLE;
  }
}

// enterError: face + display + motion, then either speak (→ SPEAKING) or
// set audioDone + ERROR for display-only errors (kErrTtsFailed is "").
//
// Simplified from the plan's double-assignment pattern: SPEAKING is used
// directly for spoken errors; ERROR is only used when there is no speech
// (e.g. kErrTtsFailed == "").  The ERROR case in tickStateMachine drains
// g_audioDoneFlag back to IDLE.
static void enterError(const char* spoken, const char* exprTag) {
  Serial.printf("ERR state: %s\n", spoken ? spoken : "");
  face.setExpression(std::string(exprTag ? exprTag : "neutral"));
  display.showStatusOverlay(String(spoken ? spoken : ""), 0xF800 /* red */);
  motion.pauseIdle();
  if (spoken && *spoken) {
    // Speak the error; audio-done fires onAudioDone() → SPEAKING → IDLE.
    tts.synth(String(spoken), [](bool /*ok*/) { onAudioDone(); });
    g_state = State::SPEAKING;
  } else {
    // No speech — just wait one tick in ERROR then clear to IDLE.
    g_state         = State::ERROR;
    g_audioDoneFlag = true;
  }
}

void initStateMachine() {
  chat.setSystemPrompt(String(kDefaultPersona) + kPersonaExamples);
  audio.setOnPlayDone([]() { onAudioDone(); });
  face.setExpression(std::string("neutral"));
  g_state = State::IDLE;
}
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

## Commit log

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2026-06-02 fix(wifi): re-register mDNS on reconnect, drop dead include, const queries
    Code-review fixes from T4:
    - tick() now calls MDNS.begin() on reconnect (ESPmDNS doesn't auto-reregister, OTA breaks otherwise)
    - drop unused #include <WiFiClient.h>
    - isConnected/getIP/getRSSI now const
    - fix off-by-one in budget-exhausted slot log
    - correct misleading "non-blocking" wording in begin() doc
    [WifiManager.cpp]
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2026-06-02 fix(portal): wire exit flag, add voicevox enum, textarea for persona, fix typos
    Code-review fixes from T6:
    - main.cpp: consume portal.exitRequested() → end() + ESP.restart() so the
    web UI's "Exit Config Mode" button actually reboots out of AP mode
    - CaptivePortal.cpp: add FieldType::Text + 'text' case in app.js renderField
    so persona renders as a 6-row textarea instead of single-line input
    - CaptivePortal.cpp: kTtsProvOptions += voicevox (Phase 2 fallback, persists
    via portal even though TtsClient T9 won't route it until Phase 2 lands)
    - comment typo: "16 spec keys" → "17 spec keys" (2 sites)
    [CaptivePortal.cpp, main.cpp]
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2026-06-02 feat(audio): MP3 → I²S player with onPlayDone callback
    Cherry-picked and adapted from Jarvis AudioPlayer. Namespace stkchan,
    raw-bytes play() API (no Mp3Buffer dependency), 256 KB PSRAM buffer
    via kMp3MaxBytes, gain=4.0 (PR #57), 25 ms decode-budget starvation
    fix (PR #56), onPlayDone drives SPEAKING → IDLE per spec invariant.
    [AudioPlayer.cpp, main.cpp]
2026-06-02 fix(tts): call http.end() even on http.begin failure; log PSRAM fallback
    Code-review fixes from T9:
    - synthOpenAi / synthEleven now call http.end() before the early return
    on http.begin failure (HTTPClient may have partial state — defensive)
    - psramAlloc logs when it falls back to internal heap so memory pressure
    is visible in field diagnostics
    [TtsClient.cpp]
2026-06-02 fix(stt): call http.end() even when http.begin fails
    Same defensive pattern as TtsClient (commit eab88b4) — HTTPClient may
    have partial state even when begin() reports failure.
    [SttClient.cpp]
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2026-06-03 fix: ship-blocker + ship-readiness from final cumulative review
    Critical:
    - main.cpp: call audio.begin() — without it, the AudioPlayer ok_ flag
    stays false and every play() returns false silently; device would
    run STT + chat but produce no sound at all
    Important:
    - state_machine: render "speaking..." overlay before tts.synth() so the
    display matches the audible state (previously stuck on "thinking...")
    - ChatClient: strip trailing slashes from chat_host before URL build to
    avoid //api/chat when users provision with a trailing slash
    - SttClient: document setInsecure() as a Phase 2 cert-pinning deferral,
    matching the comment style in TtsClient
    - WifiManager: seed s_was_connected f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
    [ChatClient.cpp, SttClient.cpp, WifiManager.cpp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]
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2026-06-03 fix(face): stub Face — Avatar drawLoop SPI race still crashes after T19 stub
    The earlier Display::* no-op fix didn't address the root cause. The
    Avatar drawLoop FreeRTOS task still races whatever happens on the main
    task (g_avatar.setExpression updates, plus possibly internal Avatar
    state mutation between draws) and trips an xQueueGenericSend mutex
    assert in Bus_SPI::endTransaction.
    Stubbing the whole Face module for v1 so the device boots, captures
    audio, runs STT/Chat/TTS, and plays back without crashing. The screen
    will show whatever M5.begin() leaves there — no animated face.
    Proper fix is either:
    (a) Stop using Avatar's auto-start drawLoop. Call g_avatar.draw()
    manually fr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
    [Face.cpp]
2026-06-03 fix(audio,chat): proper I2S speaker/mic handshake + 60s chat timeout
    Two issues caught by the first end-to-end smoke run:
    1) Stack-canary panic in spk_task (LoadProhibited) during MP3 playback
    after a press-and-record cycle. CoreS3 shares I2S0 between speaker
    and mic. M5.Mic.begin() inside MicRecorder::start() invalidates the
    speaker's DMA descriptors, M5.Mic.end() doesn't restore them, and the
    next audio.play() trips spk_task on stale state. Fix by following the
    M5Unified handshake:
    start(): M5.Speaker.end() before M5.Mic.record()
    stop(): M5.Speaker.begin() after M5.Mic.end()
    Also restore the speaker on the mic.record-failed path so a failed
    capture doesn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
    [MicRecorder.cpp, config.h]
2026-06-03 fix(audio): re-apply speaker config in play() — static after mic cycle
    MicRecorder::stop() restores the speaker with a bare M5.Speaker.begin()
    which loses the AudioPlayer's sample-rate (kSampleRate=24000) and
    virtual-channel config. Result: TTS playback came out as static after
    the first press-and-record cycle because the speaker was running on
    defaults instead of the 24 kHz / vch=0 / gain=4.0 setup AudioPlayer::
    begin() had established at boot.
    Self-heal in play() by re-applying M5.Speaker.config() + .begin() +
    SetGain at the start of every track. Idempotent on first call, restores
    config on every subsequent press.
    [AudioPlayer.cpp]
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2026-06-03 fix(audio): expose AudioPlayer::reapplySpeakerConfig, use from MicRecorder
    The previous attempt to re-init the speaker inside play() left M5.Speaker
    in a state that produced no audio at all (likely because the bridge's
    AudioOutputM5Speaker state didn't survive being re-init'd mid-track).
    Cleaner approach: expose a public reapplySpeakerConfig() on AudioPlayer
    that re-runs the speaker config (sample rate, vch, gain) but leaves the
    bridge intact. MicRecorder::stop() calls it instead of a bare
    M5.Speaker.begin(). Same call also covers the failed-mic-start path.
    [AudioPlayer.cpp, MicRecorder.cpp]
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2026-06-03 fix(audio): force volume 200 on speaker init — defaults too quiet to hear
    After tracking down the silent-but-completes playback: M5.Speaker.begin()
    appears to reset per-channel volume to a near-zero default on the CoreS3
    after an end()/begin() cycle (i.e. post-mic). Set setVolume(200) (0-255)
    explicitly in both begin() and reapplySpeakerConfig() so the speaker is
    always at a known-audible level when playback starts.
    [AudioPlayer.cpp]
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2026-06-03 feat(face): cheap lip-sync — AudioPlayer drives mouth during playback
    Sinusoidal mouth open ratio (~6 Hz) for the duration of MP3 playback,
    mouth closes on track_done. Not amplitude-tracked — just "the mouth is
    moving when the speaker is speaking", which reads correct at glance.
    Real amplitude-driven sync would tap AudioOutputM5Speaker::flush() and
    compute the per-chunk RMS or peak; deferred for later.
    [AudioPlayer.cpp]
2026-06-03 feat(face): smaller eyes, blink → thin white line
    - Eye size: 80x80 → 50x50, repositioned for the smaller footprint.
    - Blink rework: drop the bg-colored eyelid rectangles, instead animate
    the eye's own height down to a thin horizontal line (4 px) and back,
    with Y adjusted so the eye contracts toward its center. Pupil hides
    itself once the eye is below ~⅔ height so the closed state reads as
    a clean white line on black instead of "white capsule with a black
    slit clipped inside".
    [Face.cpp]
2026-06-03 feat(face): expressive mouth — lv_line w/ per-expression curves
    Replace the rectangle mouth with an lv_line of 7 control points.
    Each ExpressionMap tag gets its own curve table (per-point Y offsets +
    optional override color):
    neutral ─────── flat
    happy ∪ smile (ends up, middle down)
    sad ∩ frown (ends down, middle up)
    angry /\/\ jagged, red
    doubt / tilted up-left
    sleepy ___ small flat low
    setMouthOpen() now adds a per-point bow on top of the expression curve
    (peaks 22 px at the middle, tapers to 0 at the corners), so lip-sync
    during TTS reads as the mouth opening on top of whatever emotional
    shape is curre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
    [Face.cpp]
2026-06-03 fix(face): bigger pupils + squatter eyes — less wide-eyed startle
    Resting eyes read as "surprised" when the pupils are small dots inside
    big white circles. Bump pupil 18→32 and shrink eye height 50→42 (with
    width 48) so the pupils dominate the visible eye and the overall shape
    is slightly oval — closer to a relaxed neutral than a startled stare.
    [Face.cpp]
2026-06-03 fix(face): smaller eyes, pupils nearly fill — less bug-eyed
    Eye footprint 48x42 → 38x32. Pupil 32x32 → 30x26, now almost completely
    fills the eye so the visible white is just a thin rim. Should read as
    chill/relaxed rather than the wide-eyed bulge of the previous iteration.
    [Face.cpp]
2026-06-03 feat(menu): swipe-up reveals menu button → settings screen w/ volume
    UI flow:
    - Press-and-hold anywhere on the face screen → press-to-talk (unchanged).
    - Touch+drag from the bottom 50 px upward by >=60 px → swipe gesture
    cancels the in-flight press (via new onPressCancel FSM event) and
    reveals a floating "Menu" button at the bottom of the face screen
    for 3 s.
    - Tap the Menu button → slide-in to MenuScreen (LVGL screen #2).
    - MenuScreen: title "Settings", volume slider 0-100%, Back button.
    - Volume slider writes M5.Speaker.setVolume() immediately and persists
    to NVS (kNvsSpkVolume) so it survives reboot.
    - AudioPlayer.begin() and reapplySpeakerConfig() now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
    [AudioPlayer.cpp, Face.cpp, config.h]
2026-06-03 fix(menu): loosen swipe thresholds + add diagnostic logs
    Swipe wasn't firing on the device. Lowered:
    - start-Y from 180 → 120 (any touch on the bottom half is eligible)
    - upward dy from 60 → 40 (less of a drag needed)
    and added [Touch] serial logs on each press-down + on swipe detection
    so we can see exactly what touch coords M5.Touch is returning if it
    still doesn't fire.
    [main.cpp]
2026-06-03 fix(face): make menu button impossible to miss + diagnostic logs
    Swipe detection was working (per serial diagnostic) but the menu button
    appears not to have been visible.
    - Size 100x36 → 200x60 so it takes up the bottom strip rather than a
    small lozenge.
    - Add a 3 px white border + bigger radius for contrast against the
    near-black face background.
    - Auto-hide 3 s → 5 s so it's easier to tap.
    - lv_obj_move_foreground() at both creation and reveal to make sure
    nothing else (mouth line z-ordering) covers it.
    - Log [Face] Menu button revealed / Menu button tapped /
    Menu button auto-hidden so we can correlate behavior with serial.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
    [Face.cpp]
2026-06-03 fix(face): drop lv_timer for menu auto-hide — use millis() polling
    lv_timer_create + lv_timer_set_repeat_count(1) was firing the callback
    within ~6 ms of creation instead of after 5 s (logs showed "revealed"
    and "auto-hidden" 6 ms apart). Either an LVGL v9 quirk or our timer
    context (created outside lv_timer_handler) wasn't computing the next-
    fire time correctly.
    Replaced with a plain millis() comparison in Face::tick(now), called
    from main loop() — guaranteed to behave the way we expect.
    [Face.cpp, main.cpp]
2026-06-03 feat(v2a): drop hotspot — USB-serial WiFi provisioning + LAN control server
    No more captive-portal AP. New onboarding flow:
    - First boot with no creds: firmware waits on USB serial for a JSON line
    {"ssid":...,"psk":...} (multi-slot + a few config keys also accepted),
    persists to NVS, reboots. Face stays alive showing a setup prompt.
    - tools/provision-serial.py sends it over the same COM port you flash on.
    Web server reworked from AP captive portal to an always-on LAN control
    server (CaptivePortal::beginLan): same static UI + /api/config + /api/wifi
    routes, but bound on the station IP with a plain 404 instead of the
    captive redirect, no softAP, no DNS catch-all. Started once WiFi conne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
    [CaptivePortal.cpp, main.cpp, provision-serial.py]
2026-06-03 fix(v2a): always-on serial reprovisioning + script retry/diagnosis
    Two onboarding robustness fixes found during first hardware test:
    1) Once any creds were saved (even a wrong password), the device no
    longer entered serial provisioning — and with WiFi down the web UI is
    unreachable, so a bad password was unrecoverable without an NVS erase.
    Fix: loop() now always accepts a provisioning line over USB serial
    whenever WiFi is not connected (pollSerialProvisioning). USB is a
    permanent escape hatch. runSerialProvisioning reuses the same poller.
    2) provision-serial.py sent once after 0.5 s, but opening the port resets
    the ESP32 and it needs ~2 s to boot. Now resends every 2.5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
    [main.cpp, provision-serial.py]
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2026-06-04 fix(audio): actually apply decoder gain; fix(web): silence /api static-stat spam
    Volume — the real ceiling:
    AudioOutputM5Speaker::ConsumeSample copied decoded PCM samples raw and
    never multiplied by the gain, so SetGain(kDecoderGain) was a silent no-op
    — effective gain was always 1.0×. The only working loudness control was
    M5.Speaker.setVolume, already pegged at 255 (amp max) when the slider hit
    100%, which is why bumping kDecoderGain did nothing. Now amplify() applies
    the gain (with hard clamp) per sample, breaking past the setVolume ceiling.
    Set kDecoderGain to a real 4.0× (7.0 would hard-clip now that it bites).
    NOTE: Project-Jarvis has the identical latent bug — its AudioPlayer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
    [AudioPlayer.cpp, CaptivePortal.cpp]
2026-06-04 feat(servos): pre-stage SERVO2 module wiring (Wire1 on G43/G44)
    M5Stack Module13.2 Servo2 on CoreS3. Per the official compatibility chart
    the module I2C is a FIXED M-Bus connection: SDA→G43, SCL→G44. Drive it on
    Wire1 (secondary I2C) so it doesn't collide with the CoreS3 internal Wire
    (display/touch/power). PCA9685 at 0x40 (confirm vs datasheet on arrival).
    Hardware not in hand yet — module is ordered (the canonical Stack-chan
    servo base was too big for the enclosure). Without it, init fails
    gracefully as before, just on the correct bus now. Flash + test when it
    arrives; the control-panel head sliders are already wired to it.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
    [Servos.cpp]
2026-06-04 feat(v2d): streaming TTS — decode MP3 off the wire as it arrives
    Replaces download-then-play with a streaming source so playback starts on
    the first decoded frame instead of after the full MP3 download. Cuts
    time-to-first-audio noticeably for the spoken reply.
    - TtsStreamSource (AudioFileSource) owns the HTTP/TLS client and reads the
    response body incrementally in read(); returns bytes-available without
    busy-blocking the main loop, clean EOF via HTTP/1.0 connection-close.
    - AudioPlayer::playStream(void* src) reuses the decode-in-tick machinery
    with an externally-owned source (no PSRAM copy, no kMp3MaxBytes cap →
    also handles longer utterances). teardown_track now deletes the sou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
    [AudioPlayer.cpp, TtsClient.cpp]
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2026-06-04 fix(power): use battery voltage, not AXP2101 fuel-gauge %, for low-batt cue
    CoreS3's M5.Power.getBatteryLevel() reads low even on a full pack, so the
    low-battery cue mis-fired. Now driven by getBatteryVoltage() (direct ADC):
    - Warn only below kLowBattMv (3500 mV), re-arm above kLowBattClearMv (3700),
    and never while on external power (getVBUSVoltage >= 4000 mV or isCharging).
    - Debounced ~10 s sustained + 30 s boot grace to ignore AXP settling.
    - Face % and web Battery tile now derived from voltage (batteryPctFromMv);
    /api/status also exposes battery_mv + vbus_mv, and a serial [PWR] line logs
    vbat/vbus/chg each tick for verification.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
    [CaptivePortal.cpp, config.h, main.cpp]
2026-06-04 fix(power): set cfg.output_power=false (BUS_OUT_EN=0) so it doesn't drain battery
    Root cause of the false "battery low": CoreS3 booted with M5Unified's default
    cfg.output_power=true -> setExtOutput(true) -> AXP2101 BUS_OUT_EN=1, i.e. the
    "USB INPUT / BUS OUTPUT" power-path: the AXP boosts the battery out to the
    Grove/M-Bus 5V port. On battery that drains the pack and skews the reported
    charge/discharge state, so it reads low even when full.
    We don't power bus modules from the Core (servo board has its own 5V), so
    select "USB INPUT / BUS INPUT" (BUS_OUT_EN=0): draw/charge from USB-C, don't
    source the bus. The voltage-based metering + cue gating from the prior commit
    stay as a safety net.
    Co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
    [main.cpp]
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2026-06-04 fix(power): revert to output_power=true — false disables the battery boost
    Correcting a1797fb: on CoreS3, M5Unified setExtOutput() (_core_s3_output in
    Power_Class.cpp) clears AW9523 BUS_EN and, when BUS_EN hits 0, also clears
    BOOST_EN — the SY7088 boost that steps the battery up to the 5V system rail.
    So output_power=false makes the device run only on USB and die on battery.
    Keep the default true. The earlier false "battery low" was the unreliable
    fuel-gauge %, already addressed by voltage-based metering, not this flag.
    (Field root-cause of the dead-on-battery symptom was actually a reversed-
    polarity aftermarket LiPo; M5's own cell works. This revert removes the
    latent firmware bug reg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
    [main.cpp]
2026-06-04 fix(power): output_power=false again — true was the bare-USB shutdown cause
    Reverts 9309aaf. My 9309aaf reasoning was wrong: I blamed the original "dies on
    battery" on output_power=false, but that was a REVERSED-polarity aftermarket
    cell — the M5 cell ran fine on false. Setting true then introduced a new fault:
    on bare USB with NO battery the rail shuts down after seconds/minutes, because
    the bus boost true enables has no battery to draw from.
    output_power only gates the external bus 5V output, which this build doesn't
    use (PCA9685 is externally powered). false runs on BOTH bare USB and battery,
    so it's correct. setBatteryCharge(true)+setChargeCurrent(200) stay.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
    [main.cpp]
2026-06-04 chore(debug): roll firmware back to 8d82ae5 (pre-2026-06-04) to isolate shutdowns
    Restores src/ + data/ to the last commit before today's work, reverting all of
    today's firmware changes (battery/WiFi face indicators, voltage metering, low-
    battery cue, web battery status, and the output_power / setBatteryCharge /
    setChargeCurrent power changes). Enclosure work (hardware/) is kept.
    Purpose: the device shuts down under load and we need to know if today's code
    caused it or if it's the (missing/flaky) battery hardware. If this baseline is
    stable, a today change regressed it; if it still shuts down, firmware is
    exonerated. All reverted work remains in history (f65fb55..90c5253) to re-apply.
    Co-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
    [CaptivePortal.cpp, Face.cpp, config.h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]
2026-06-04 feat(power): re-apply battery/WiFi features; output_power=true (default)
    Root cause of the all-day power saga was finally found: NO BATTERY in the
    circuit. The CoreS3's 500 mAh cell lives in the DinBase, which was disconnected
    when the board was pulled for the StackChan build — so it browned out / latched
    off under Wi-Fi+audio current spikes (and the audio was choppy). With the
    DinBase battery reconnected it's stable. Confirmed on hardware.
    Restores today's exonerated work (reverting the debug rollback 1ce5045):
    - voltage-based battery metering + spoken low-battery cue
    - battery + WiFi status on the face (top-left) and web Status tab
    - [PWR] vbat/vbus serial log
    - setBatteryCharge(true) +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
    [CaptivePortal.cpp, Face.cpp, config.h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]
2026-06-05 feat(servos): move PCA9685 I2C to Port C (G17/G18)
    The M-Bus is occupied by the DinBase (battery), so the original M-Bus pins
    (G43/G44) aren't reachable. ESP32-S3 routes I2C to any GPIO, so drive the
    PCA9685 on Wire1 over Port C: SDA=G17, SCL=G18. Avoids Port B (G8/G9 = the
    DinBase power-button PB_IN/PB_OUT lines). Address still 0x40.
    [Servos.cpp]
2026-06-05 fix(power): output_power=false — run on USB independent of the (absent) battery
    The DinBase battery is currently out of the circuit (its switch won't power-on),
    and with output_power=true the CoreS3 destabilizes / shuts down on USB after a
    while when no healthy battery is present. output_power=false runs the system
    straight from USB, stable with or without a battery. Revert to true once a
    reliable battery is reconnected. Charging config is unaffected (AXP charger).
    [main.cpp]
2026-06-05 chore(power): revert to M5 factory-default power config
    Remove all AXP2101 overrides (cfg.output_power, setBatteryCharge,
    setChargeCurrent) so M5.begin() configures power exactly as M5 ships it. The
    shutdowns traced to hardware (faulty DinBase / damaged board), not these
    settings. Read-only [PWR] vbat/vbus log kept for hardware diagnosis.
    [main.cpp]
2026-06-05 fix(power): output_power=false for batteryless USB (bare Core dies on true+no-battery)
    Hardware finding: the bare CoreS3 (DinBase removed, no battery) on factory
    output_power=true ran ~3 min + a full voice turn, then died — the bus boost
    wants a battery present. With a battery, true is stable. Since we're running
    batteryless on USB, false runs the system straight from USB. Decisive test:
    if the bare Core now runs indefinitely, the Core is healthy (DinBase was the
    fast-kill culprit); if it still dies, the Core is damaged.
    [main.cpp]
2026-06-05 chore(power): factory-default power again — stock firmware proves hardware is fine
    The user flashed the stock CoreS3 demo firmware and it runs stably WITH the
    DinBase — so the CoreS3 and DinBase are healthy (my "damaged hardware" verdict
    was wrong). The crashes are in our firmware or the servo-test wiring. Reset to
    M5 factory-default power (output_power default true, matching stock) as the
    clean baseline for an apples-to-apples comparison.
    [main.cpp]
2026-06-05 debug: add reset-reason at boot + heap/psram to [PWR] log
    Stock firmware is stable, ours crashes after a couple voice turns → it's our
    firmware. Instrument to find the cause before fixing:
    - [BOOT] reset reason: prints esp_reset_reason() at boot (survives the USB-CDC
    drop) → distinguishes PANIC(4)/TASK_WDT(6)/BROWNOUT(9) when it reboots.
    - [PWR] now logs free heap / min-free-heap / free psram → detects a per-voice-
    turn memory leak (prime suspect: WAV/MP3/JSON/HTTPS buffers).
    [main.cpp]
2026-06-05 debug: log largest-free-block (maxblk) too — crash happens at idle as well
    It crashes even while idle, so it's a periodic/background cause (connectivity
    probe every 30s, web-server polling, OTA, or a slow leak/fragmentation), not
    the voice path alone. Added ESP.getMaxAllocHeap() to [PWR] to catch TLS
    fragmentation (largest block shrinks while total free stays high).
    [main.cpp]
2026-06-05 diag: AXP2101 power-fault forensics for the stays-off crash
    The crash signature (screen black, stays off, no serial, no self-reboot) is a
    PMIC rail latch-off, not a CPU fault — esp_reset_reason() is blind to it. Read
    the AXP2101 status (0x00/0x01) + latched IRQ (0x48-0x4A) registers at boot, which
    persist in the always-on domain across the off period (recover via power button,
    not by yanking power). Also log signed battery current in the [PWR] trail so a
    discharge spike before the last line flags a current-limit brownout. Read-only;
    no change to power behavior.
    [main.cpp]
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
